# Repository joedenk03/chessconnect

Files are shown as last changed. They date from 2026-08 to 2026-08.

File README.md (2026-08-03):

# ChessConnect

A self-contained physical chess board that lets a local player face any Lichess.org
opponent over the internet, with both players' moves relayed to the physical board
in real time.

Senior capstone project at the University of Pittsburgh at Johnstown, 2024–2025.

https://github.com/user-attachments/assets/ddd3d065-473c-4527-940a-21a858fc336b

*Live demo at the University of Pittsburgh at Johnstown Senior Capstone Showcase — Joseph and Brendan walk through the system while playing a live game (Joseph on the physical board, Brendan on Lichess).*

## What It Does

ChessConnect combines a traditional wooden chess board with an internal
Cartesian gantry and electromagnet, allowing a local player to physically move
pieces against a remote opponent playing over Lichess.org — with no additional
software required on the remote player's end.

* The **local player** moves pieces normally. Reed switches under every square
detect the moves; the Arduino interprets them and sends them to Lichess.
* The **remote player** moves in their Lichess app or browser. When their move
arrives, the internal XY gantry positions an electromagnet under the piece,
turns on, drags the piece to its destination, and turns off.
* The **LCD screen** displays the in-game clock, current game status, and
handles the game setup UI (opponent selection, time controls, etc.).
* The system operates as a standalone device — once linked to a Lichess
account and connected to WiFi, it needs no external computer, phone, or app.

## Photos

|||
|-|-|
|Board playing view|Internal gantry|
|External playing view|Internal cabinet with XY gantry, electromagnet, and reed switch matrix|

## System Overview

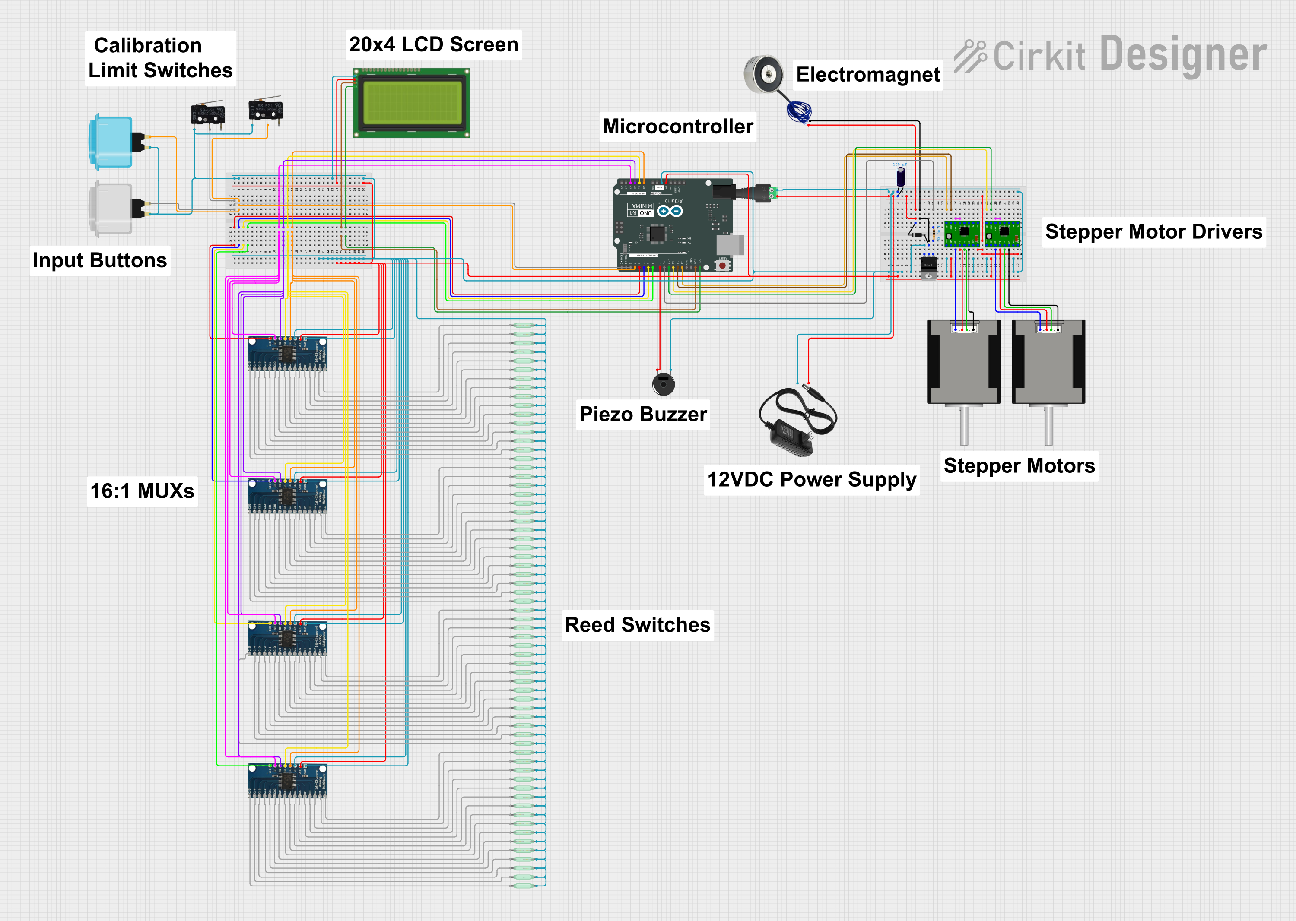
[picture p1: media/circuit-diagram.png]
Circuit diagram


### Key Components

|Component|Role|
|-|-|
|Arduino Uno R4 WiFi|Main microcontroller — inputs, game logic, Lichess API integration|
|Reed switch matrix (8×8)|Detects piece presence on each square via magnets in each piece base|
|4× 16:1 analog multiplexers|Read the 64 reed switches with a small pin budget|
|XY stepper gantry|Positions the electromagnet beneath the board|
|Electromagnet (TIP120 BJT drive)|Attracts pieces from below for automated moves|
|2× stepper drivers + steppers|Drive the X and Y axes of the gantry|
|20×4 LCD|Game setup UI, clock display, status messages|
|Limit switches|Homing and calibration for the gantry|
|Push buttons|User input for menu navigation|

Full block diagram and component descriptions in the capstone poster
([media/poster.pdf](media/poster.pdf)).

## Repository Structure

```
chessconnect/
├── README.md
├── .gitignore
├── firmware/
│ ├── chessconnect.ino
│ ├── secrets.h.example
│ └── secrets.h (local file, gitignored)
├── media/
│ ├── topdown-view.jpg
│ ├── internal-view.jpg
│ ├── circuit-diagram.png
│ └── poster.pdf
├── hardware/
│ └── models/
│ ├── stl/
│ │ ├── king.stl
│ │ ├── queen.stl
│ │ ├── rook.stl
│ │ ├── bishop.stl
│ │ ├── knight.stl
│ │ └── pawn.stl
│ └── fusion/
│ ├── king.f3d
│ └── ...
└── docs/
├── design-report.pdf
├── functional-requirements.pdf
├── testing-and-analysis.pdf
├── final-report.pdf
└── final-presentation.pdf
```

## Piece Fabrication

The playing pieces are 3D-printed from custom CAD models designed in Fusion 360.
Each piece has an embedded neodymium magnet in its base to interact with the
reed switches and be moved by the internal electromagnet.

CAD source files and print-ready STLs are in [`hardware/models/`](hardware/models/).

https://github.com/user-attachments/assets/cc7fb758-c390-4b25-9f52-523a92acfec9

## Firmware

The main firmware lives in [`firmware/chessconnect.ino`](firmware/chessconnect.ino).
It runs on an Arduino Uno R4 WiFi and handles:

* Setup and calibration of the XY gantry via limit switches
* Reed switch matrix scanning through four 16:1 muxes to detect piece positions
* Internal chess board state tracking and legal move interpretation
* Lichess REST API integration for game creation, move submission, and game
state streaming (`/api/challenge/`, `/api/board/game/`, `/api/board/game/stream/`)
* Motor control routines for file, rank, and diagonal moves via the AccelStepper
library, including special-case handling for castling and en passant
* LCD UI for game setup (opponent selection, time controls) and in-game display
(clock, status, error messages)
* Electromagnet control via a TIP120 BJT driver

### Building and Running

The firmware requires several Arduino libraries:

* **WiFiS3** and **WiFiSSLClient** — Arduino Uno R4 WiFi networking
* **ArduinoJson** — parsing Lichess API responses
* **LiquidCrystal_I2C** — 20×4 LCD control
* **AccelStepper** — stepper motor control with acceleration profiles
* **Wire** — I²C for the LCD

Before building:

1. Copy `firmware/secrets.h.example` to `firmware/secrets.h`
2. Fill in your WiFi SSID, WiFi password, and Lichess personal API token
(create a token at https://lichess.org/account/oauth/token with scopes
`challenge:read`, `challenge:write`, `board:play`)
3. Open the sketch in the Arduino IDE and upload to an Arduino Uno R4 WiFi

`secrets.h` is gitignored — it will not be tracked by git or pushed to any
public repository.

## Validation

ChessConnect was validated against a set of functional requirements defined
during the design phase. Testing included:

* Full games played against Lichess opponents (both human and bot), with
dozens of complete games recorded during system testing
* Verification of all special moves (castling, en passant, promotion)
* Board calibration procedures across multiple power cycles
* Error handling for illegal moves and mid-game piece disruption
* Automated piece movement speed verification (below)

https://github.com/user-attachments/assets/c93962c8-b26c-460b-896f-1c7d04267033

*Piece movement speed verification: an automated capture demonstrating the XY gantry, electromagnet timing, and post-move board state recognition. Used to verify the piece movement speed functional requirement.*

Full validation results in [`docs/testing-and-analysis.pdf`](docs/testing-and-analysis.pdf).
The complete project write-up, including background, design decisions, and outcomes, is in [`docs/final-report.pdf`](docs/final-report.pdf).

## Team

ChessConnect was developed as a senior capstone project by
**Joseph Denk** and **Brendan Jugan**, advised by Dr. Laura Wieserman,
at the University of Pittsburgh at Johnstown (2024–2025).

**Contribution breakdown:**

* **Joseph Denk** (this repository owner): Hardware design and fabrication —
board construction, circuit design and assembly, component selection and
specification, breadboard prototyping, mechanical integration. Firmware
contributions including architectural and program-flow input and
implementation of specific subsystems.
* **Brendan Jugan**: Primary firmware development, Lichess.org API integration,
game state management, and user interface logic.

Both team members contributed to overall system design, testing and
validation, and documentation.

## Documentation

The [`docs/`](docs/) folder contains the full set of project deliverables:

- [`design-report.pdf`](docs/design-report.pdf) — pre-build design phase report covering
  system architecture, component selection, and initial design decisions
- [`functional-requirements.pdf`](docs/functional-requirements.pdf) — formal specification
  of what ChessConnect had to do to be considered complete
- [`testing-and-analysis.pdf`](docs/testing-and-analysis.pdf) — verification results showing
  ChessConnect functioned as intended
- [`final-report.pdf`](docs/final-report.pdf) — complete project write-up covering the full
  year of design, construction, testing, and outcomes
- [`final-presentation.pdf`](docs/final-presentation.pdf) — capstone presentation slide deck

## License

Source code and documentation are provided as-is for portfolio and educational
purposes. Not affiliated with or endorsed by Lichess.org.

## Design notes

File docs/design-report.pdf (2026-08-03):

CoE 1195 Senior Project

ChessConnect

Final Design

Joseph Denk and Brendan Jugan

Department of Electrical and Computer Engineering

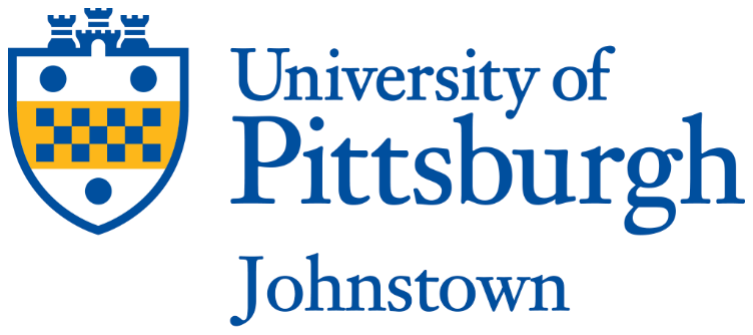
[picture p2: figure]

December 13th, 2024

Submitted to Dr. Laura Wieserman

CoE 1195 Senior Project

ChessConnect

Final Design – Bill of Materials

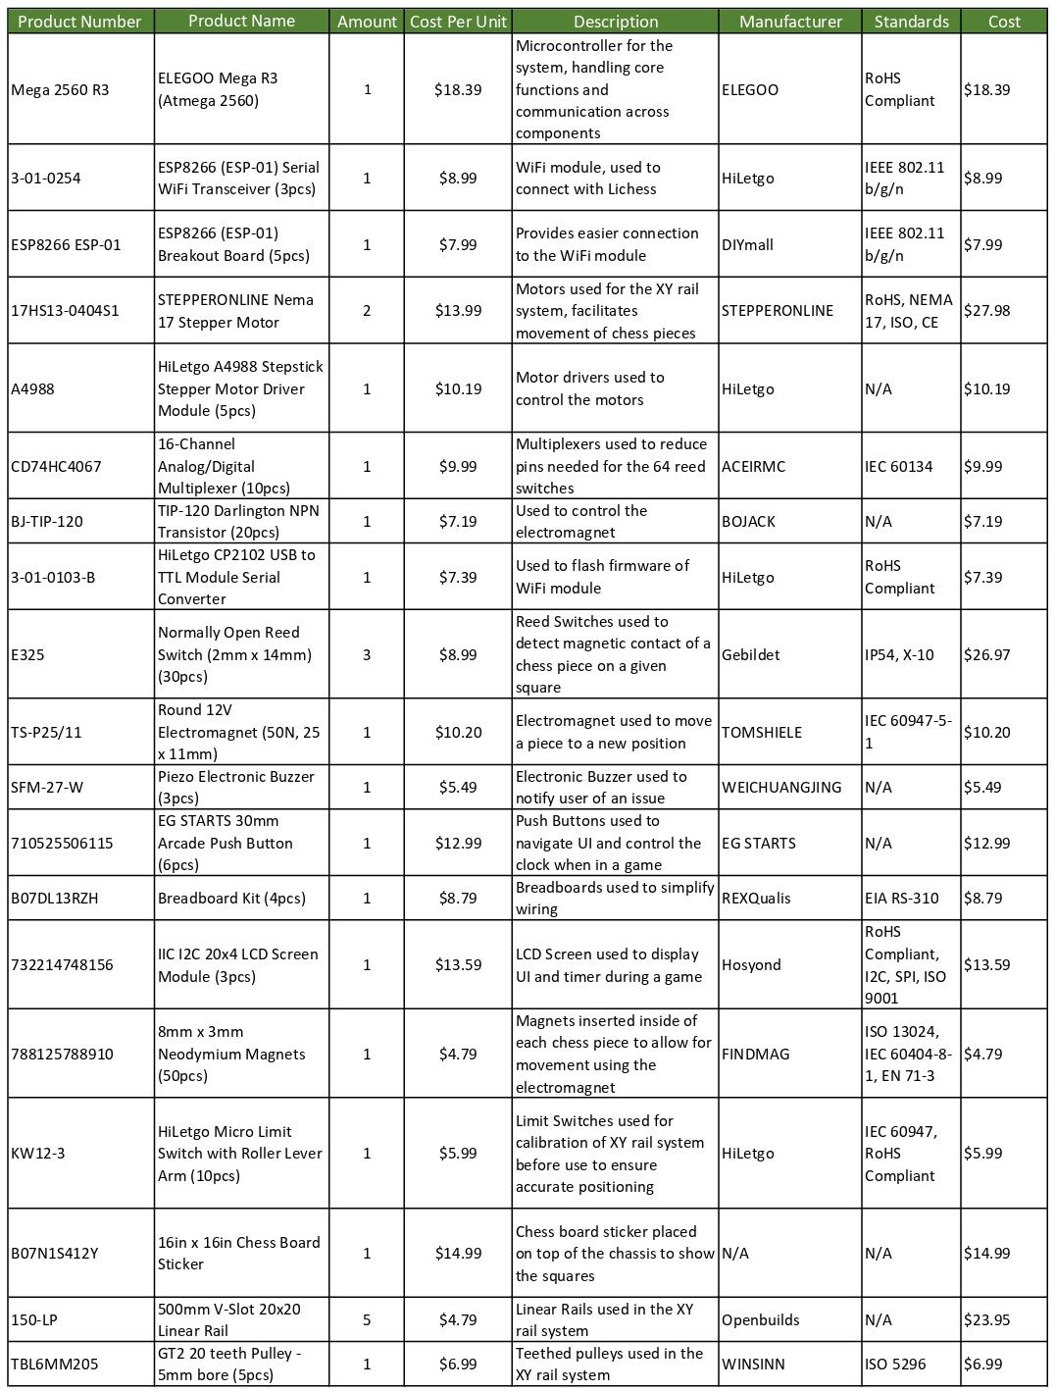
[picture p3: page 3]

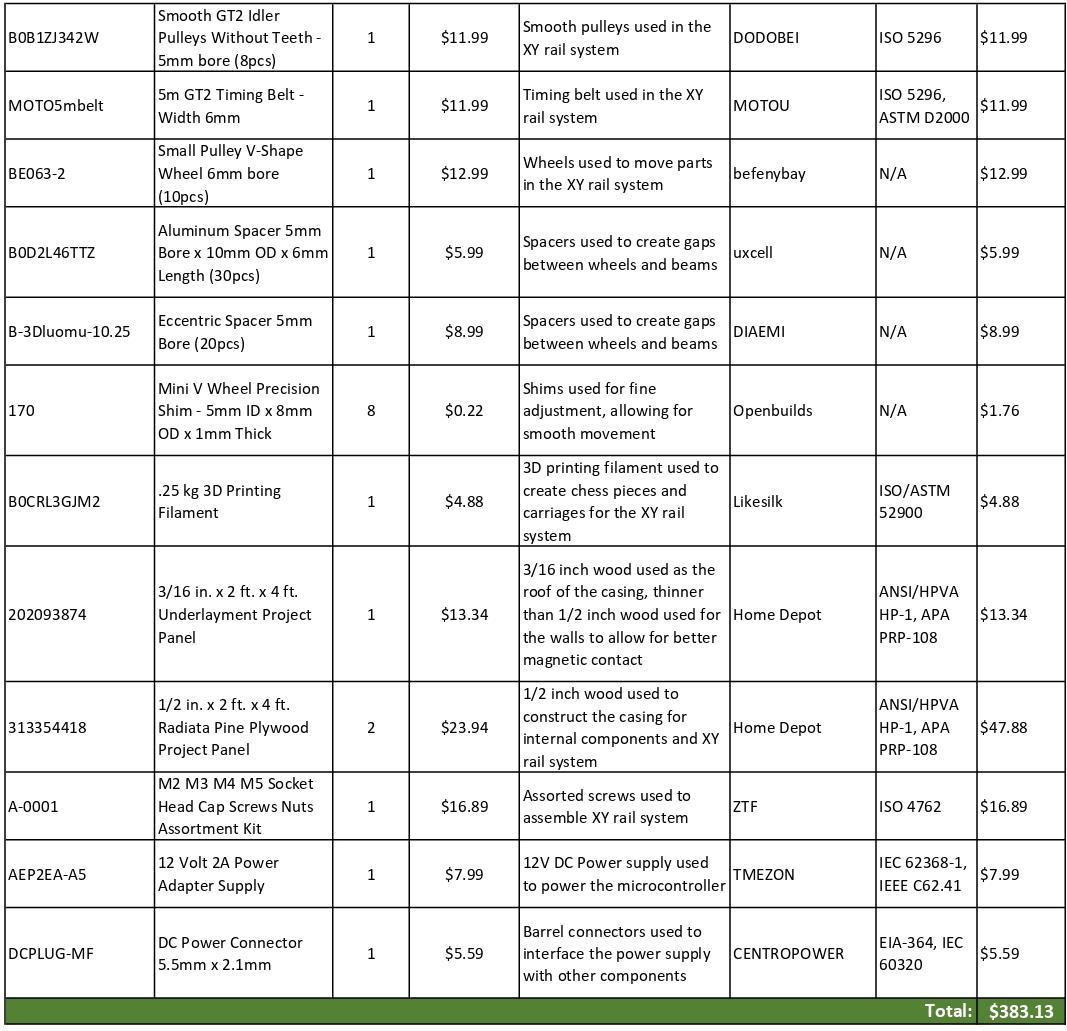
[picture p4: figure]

CoE 1195 Senior Project

ChessConnect

Final Design – Circuit Diagram

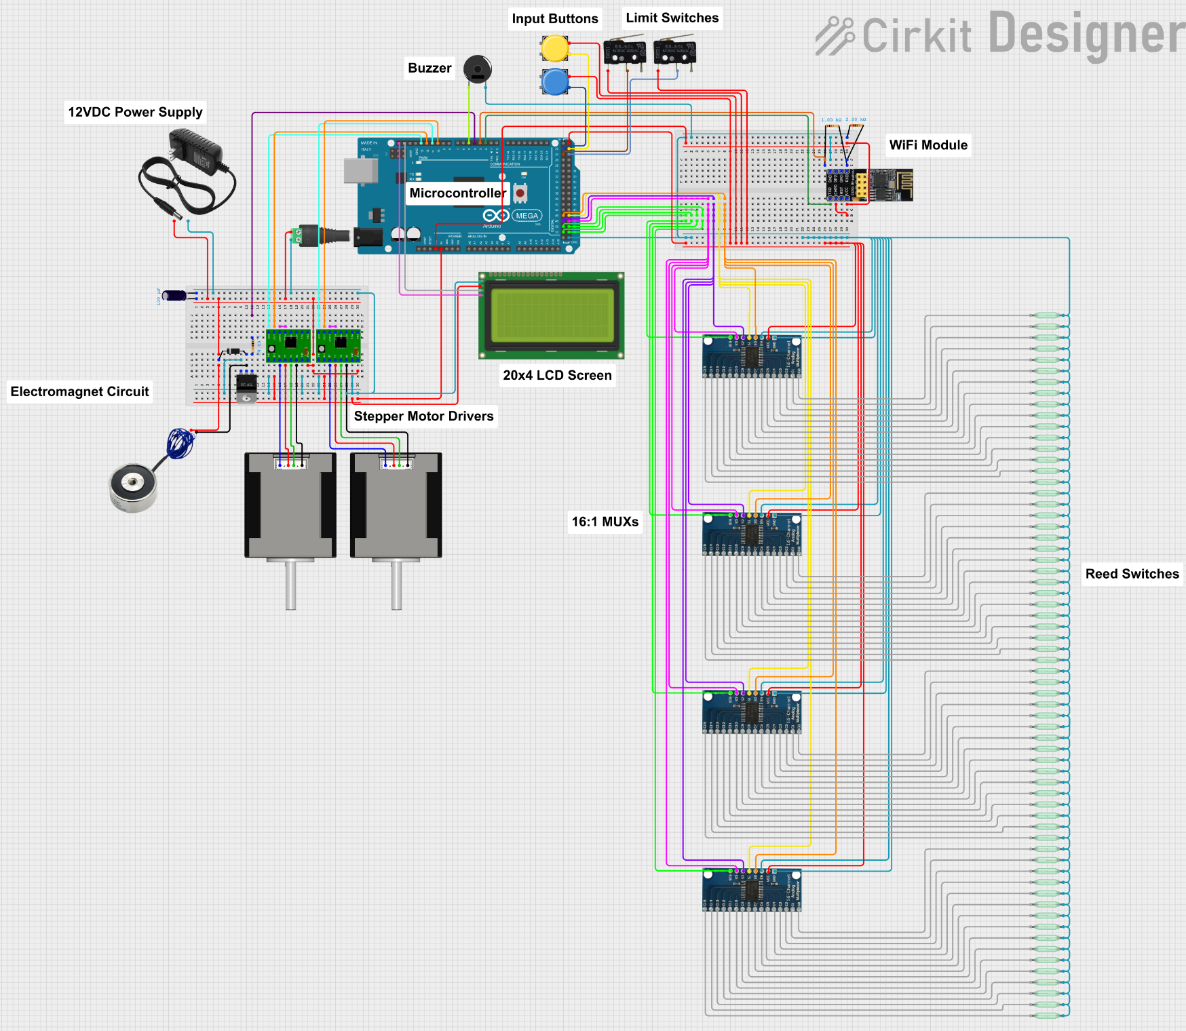
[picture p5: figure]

CoE 1195 Senior Project

ChessConnect

Final Design – Design Schematics

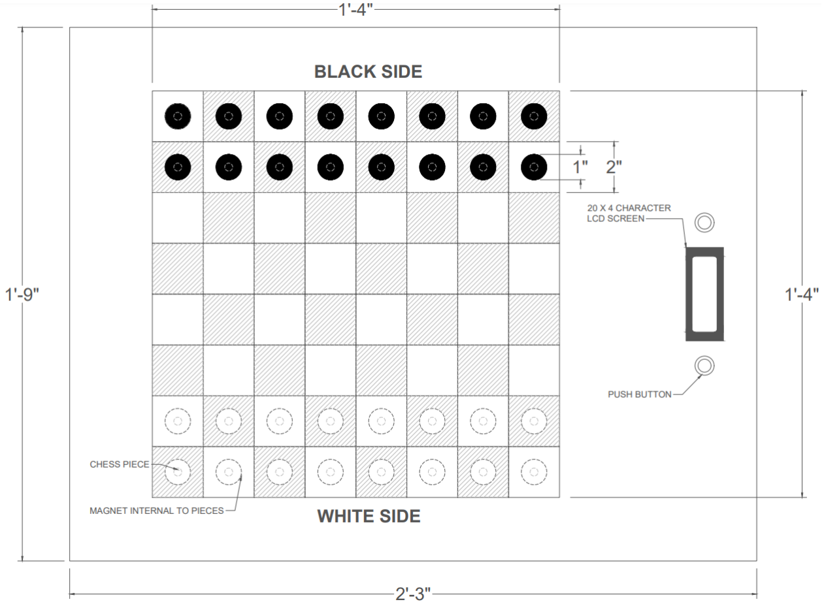
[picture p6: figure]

Fig. 1: Overall view of ChessConnect

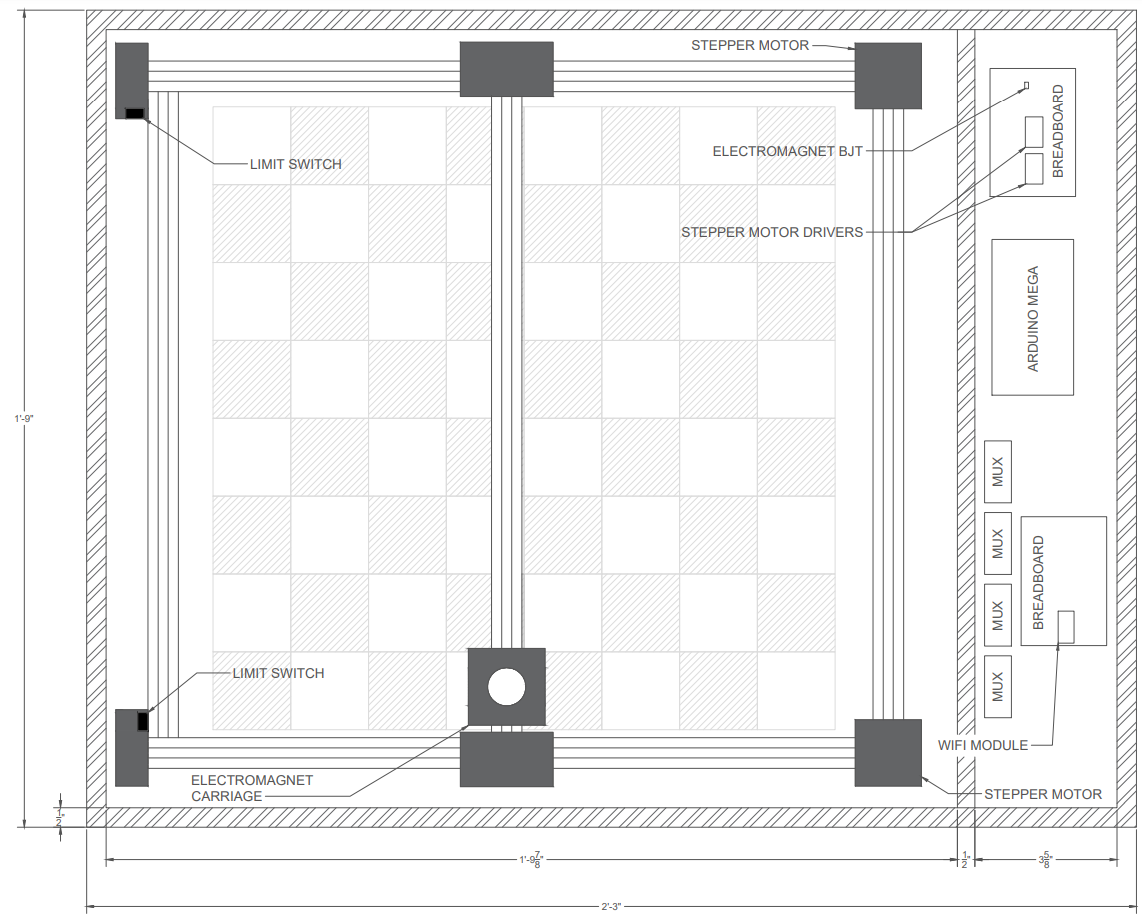
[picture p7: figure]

Fig. 2: Internal view of ChessConnect

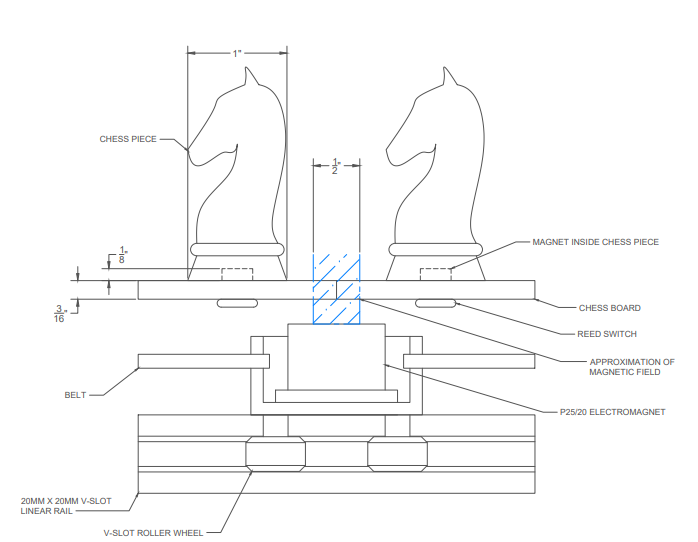
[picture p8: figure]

Fig. 3: Enlarged side view of ChessConnect

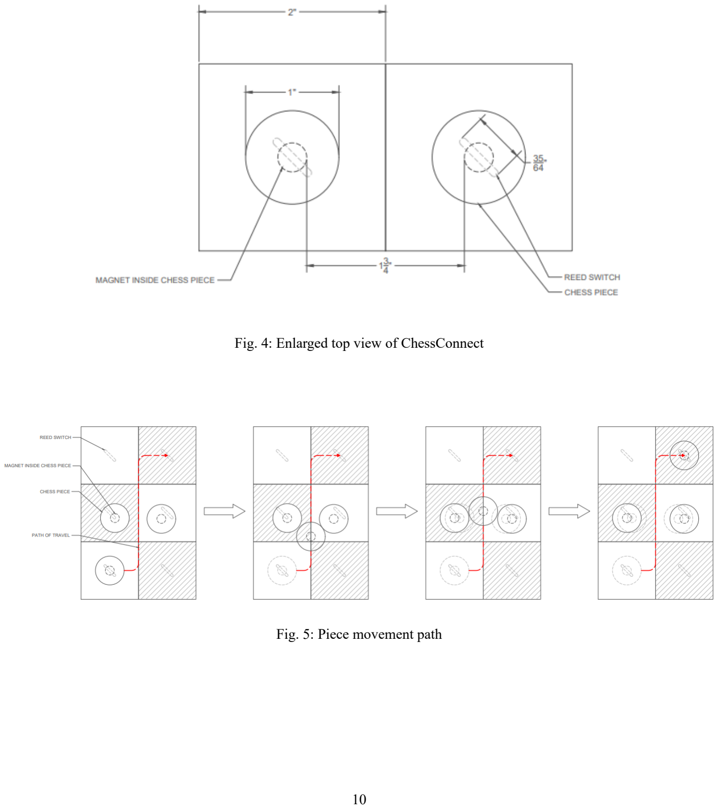
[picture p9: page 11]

Fig. 4: Enlarged top view of ChessConnect

Fig. 5: Piece movement path

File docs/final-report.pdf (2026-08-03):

## CoE 1199 Senior Project

## ChessConnect

## Final Report

## Joseph Denk and Brendan Jugan

## Department of Electrical and Computer Engineering

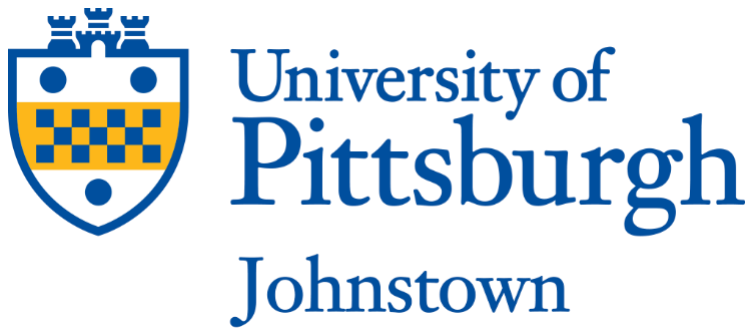
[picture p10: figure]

## April 28th, 2025

## Introduction

Chess is a game that is traditionally played over-the-board, but as humanity has

transitioned into the digital age the game has undergone many transformations that have affected

how players experience it. The most apparent of these changes has been the rise of online chess.

With the popularity of personal computers and phones, more and more people are turning to

digital chess and abandoning the traditional format.

As a result, the two formats have evolved in ways that have made them increasingly

distinct from one another. Online chess is often more convenient for users, providing them with

the ease of finding a game against an opponent of similar skill within seconds. Despite this

convenience, the format also comes with drawbacks that can impact one’s performance. For

example, many players find it easy to get distracted while playing online chess due to being

plagued by notifications, pop-ups, and advertisements which can easily break their focus. This

shorter attention span is also highlighted by the fact that online chess players prefer games with

shorter time controls. Online, fast-paced games do not effectively give players time to fully

calculate long sequences of moves and figure out a plan — a skill that is necessary for longer

time controls, which are typically used in over-the-board games. These differences in pace and

environment illustrate some of the broader distinctions between online and traditional chess;

however, even the core skillset required to play differs between the formats.

In traditional chess, players study and visualize a physical, three-dimensional board. In

contrast, online chess requires visualization of a two-dimensional board shown on a screen. The

pattern recognition necessary to visualize the board for each format is very different, as the

physicality of over-the-board games requires a level of spatial awareness that is not present when

playing online games. As such, the two formats require distinct ways of thinking and recognizing patterns. This becomes apparent when online users play an over-the-board game, wherein they

may struggle with visualizing potential moves and vulnerabilities to their pieces. Many online

chess platforms even give users the ability to draw arrows on their board, removing a key aspect

of the visualization required when playing an over-the-board game. As a result, these differences

between the two formats often make it difficult for one to transition from online to traditional

chess without facing challenges stemming from both digital and physical limitations.

The solution to this disparity is to create an electronic chess set that can be used to

translate virtual chess games into the physical realm and vice versa. Combining the aspects of

both online and traditional chess requires a specific balance between electronic assistance and

additional complexity to the traditional chess experience. This must be achieved while ensuring

the product remains convenient, easy to use, and affordable. It is this balance that ChessConnect

strives to achieve.

## Solution

ChessConnect is an electronic chessboard designed to bring a new and innovative

experience to chess players. Using the board, a chess game can be played against an online

opponent while the ChessConnect user plays on a physical board. When the user makes a move,

the board will automatically relay it to the opponent’s online game. Similarly, when the online

opponent makes a move, the pieces on the physical board will automatically move to their

updated positions. In doing this, ChessConnect allows for the convenience of online chess games

while allowing users to form good habits that are built from playing physical chess games.

As initially proposed, ChessConnect was intended to connect to an online chess service

using an Arduino Mega microcontroller along with a WiFi module. Once the board has an

established connection, the board would then connect to Chess.com to allow the user to play against online opponents while at a physical board. Move detection for the user would be done

using reed switches placed on each chess square on the underside of the board. These reed

switches would interface with magnets internal to each chess piece so that the state of the board

can be tracked in real time by scanning these switches. Once it becomes the opponent’s turn, the

board would connect with Chess.com and wait for a move to be sent by the opponent. Once a

move is sent, an internal gantry with an attached electromagnet would position itself under the

piece to be moved. It would then move this piece by turning the electromagnet on and moving to

the piece’s destination square. In the case of taking pieces or knight movement, pieces would be

sized to allow for movement on the border of squares without interfering with other pieces on the

board.

However, now that the device has been built, changes have been made to the preliminary

design of the device. The device functions nearly the same as proposed, with little to no

functional changes being made to the core concept of the project. However, a change needed to

be made to the server on which the ChessConnect user will play games. Originally, the device

was to connect to Chess.com, but during testing, it was determined that the Chess.com API was

very closed off to the public. To gain access to the API, multiple steps of documentation were

needed and resources pertaining to the use of the API were sparce. As a result, Lichess.org,

another large online chess service with an open access API, was determined to be a more suitable

server to be used for the device. This API also came with extensive documentation and examples

which made implementation much less time consuming. Along with the server change, hardware

modifications were also made to the device to make online capabilities possible. During testing,

the project group determined that the Arduino Mega and WiFi module are not capable of

interfacing with the Lichess server. While these components can successfully connect to WiFi networks and connect to multiple online servers, they are incapable of connecting to Lichess due

to the type of connection encryption used with their servers. To connect to Lichess, a root

certificate must be stored in the microcontroller, and the Arduino Mega lacks the processing

power and memory to handle this encryption process. To resolve this, the Arduino Mega and

WiFi module was returned and substituted with an Arduino UNO R4 WiFi. This microcontroller

was chosen due to its built-in ESP32 chip which is capable of interfacing with encrypted servers

like Lichess. These changes were crucial to the successful implementation of online connectivity

onto the physical board.

## Results

The completed ChessConnect system successfully fulfills its intended functionality of

bridging the gap between online and traditional chess formats. Once powered and connected to

WiFi and a Lichess.org account, the board enables users to start a new game directly from the

onboard interface. Once the match begins, the board operates exactly as specified during the

design phase. When it is the opponent’s move, the internal gantry will move under the moving

piece’s square, take it to its new square without interfering with uninvolved pieces on the board,

and position it on the destination square. When it is the user’s turn, the board will continuously

scan the reed switches and update the board state until a change is made. If the user does not

wish to make a move and wants to view options, they can browse a brief options menu allowing

them to resign the game or adjust pieces manually if many pieces have been knocked off their

space. Otherwise, once a piece is picked up, it will be determined whether the user is taking a

piece or not along with allowing them to return their piece back to its original square and make a

different move if they wish. Once a move is made, it is sent to the Lichess server and reflected in the ongoing online game. This bidirectional synchronization enables a seamless playing

experience and gives users the benefits of both online and traditional chess formats.

In addition to the core features, ChessConnect accounts for special cases that can happen

during a chess game. All unique chess moves are accounted for when making an automatic move

on the board or a user move which ensures that any type of move can be played. Furthermore, if

the user makes an illegal move, the board includes safeguards to maintain the gameplay flow and

allow the user to remedy their mistake. If an illegal move is made, the user is informed of the

invalid move via the LCD screen and prompted to put the piece(s) back. Once they have done

this, they can return to the gameplay and make another move as if the illegal move had never

happened.

## Conclusion and Recommendations

ChessConnect has reinforced many ideas and techniques learned throughout the

curriculum at the University of Pittsburgh at Johnstown. These include many different hardware

and circuit design skills, microcontroller coding and usage, and general software implementation

and practices. Along with concepts, many new skills were developed by the group members to

complete the project. These skills include soldering, API integration/interfacing, and automation

controls. The team also developed crucial testing skills which were required to take

ChessConnect from an interesting concept to a functioning prototype. For example, extensive

testing needed to be conducted surrounding the magnetic interactions that allowed the device to

work. The project team had to repeatedly test and adjust the various implementations of the

magnetic switches, electromagnet, and internal piece magnets to strike a balance that was not

only functional but also consistent. These tests also expanded the team’s knowledge of various

magnetic technologies which provided valuable insight into future changes which could potentially improve the device’s functionality. Overall, ChessConnect proved not only to be a

successful project but an important learning experience that highlighted the importance of

adaptability, hands-on development, and continuous learning.

Looking ahead, there are some future improvements that can be made to ChessConnect to

enhance the gameplay experience for the user. General build quality improvements would

greatly help not only with the overall appearance of the device but also improve functionality in

nearly all areas. Better reed switches and more suitable material to construct the chassis would

allow for more consistent piece detection, and better motors, perhaps with dampening, could also

be used in the future to reduce the vibration and sound produced during gantry movement.

Another future consideration is compatibility with different chess servers and game modes. In

the future, the project group would like to interface with other online servers like Chess.com to

allow users to have the most freedom when choosing how to play. Also, more game modes could

be implemented in the future such as game modes with unique starting positions or the

development of a ChessConnect specific game mode.

## Hardware Appendices

### Description of Components

Listed below are descriptions of the core hardware components of ChessConnect and the

function they serve to the overall device. The interaction between these components is expanded

upon in the following section – the block diagram.

Arduino UNO R4 WiFi - The Arduino microcontroller enables connection to Lichess and

acquires data from the various inputs to facilitate the user interface (UI) as well as interpret the

user’s chess moves which are then sent to the online game. Similarly, it converts the opponent’s

move from the online game into the corresponding sequence of motor and electromagnet

controls that update the piece positions.

LCD Display - The LCD Display facilitates all direct communication with the user, allowing

them to traverse through the game mode selection, check their move before sending, display

errors or illegal moves, and view options during a game.

Speaker - The internal speaker is a small, two wire piezo buzzer used solely for making simple

beeps when a piece is not detected on its destination square after an automatic move.

12V DC Power Supply - The power supply is used to convert 120V AC power from a common

wall outlet into the 12V DC power needed for various components.

Push Button (x2) - The push buttons are located on the black and white sides of the LCD

display. They are used by the user to navigate various options listed on the LCD display and to

send a move.

BJT – TIP 120 - The TIP-120 bipolar junction transistor (BJT) functions as a control switch for

the electromagnet. The higher current and voltage demands of the electromagnet necessitates that

it is powered from the 12V supply directly instead of from the Arduino pins. By connecting the

base pin of the BJT to the microcontroller and routing the supply power to the electromagnet

through the collector and emitter pins, the Arduino can control when the current to the

electromagnet flows.

Electromagnet - The electromagnet is used on the internal gantry to control piece movement.

When the opponent’s move is received, the magnet will be positioned beneath the piece, turn on,

and hold the piece as it is moved to its destination.

Stepper Motor Driver (x2) - The stepper motor drivers are used to operate the motors for the

XY rail system. These motor drivers take instructions from the microcontroller and convert them

into movements that the motor can perform.

Stepper Motor (x2) - The motors are used to facilitate the movement of the electromagnet

mounted on the XY rail system and allows for piece movement.

Reed Switch (x64) - The Reed switches are used to track the positions of the pieces during a

game. These switches are located under every square of the board, allowing them to interact with

the internal magnets of each piece. By tracking the changes in which switches are closed or open,

the microcontroller can detect how the user moves their pieces.

MUX (x4) - The 16-channel multiplexers are used to reduce the number of pins necessary to

connect the 64 reed switches to the microcontroller.

Micro Switch (x2) - The micro switches are mounted onto the gantry and are used as limit

switches for calibration. They are placed in specific positions such that the rail system can move

the electromagnet to the furthest corner of the rail system. This allows the electromagnet to have

a known position to move from

### Block Diagram

The block diagram shown below in Figure 1 details the connections between the

hardware components of ChessConnect.

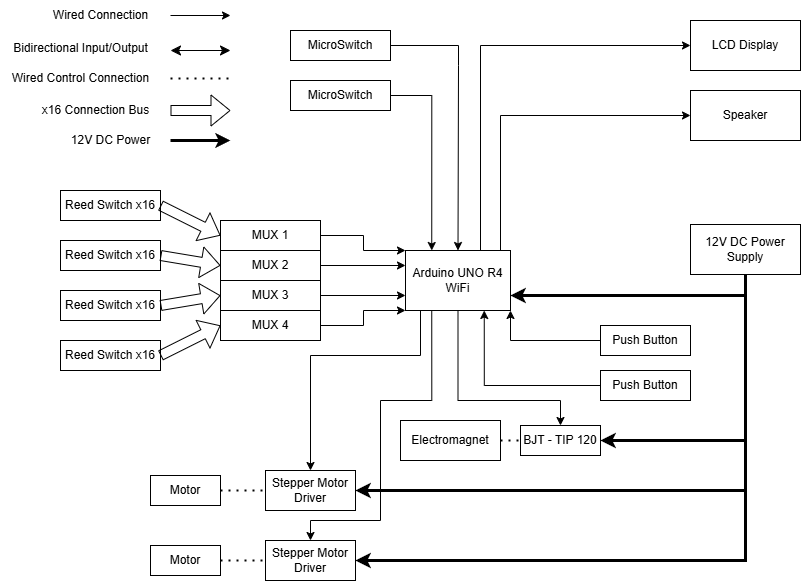
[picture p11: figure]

Fig. 1. Block Diagram

### Circuit Diagram

The circuit diagram shown below in Figure 2 outlines the connections between each

hardware component described above.

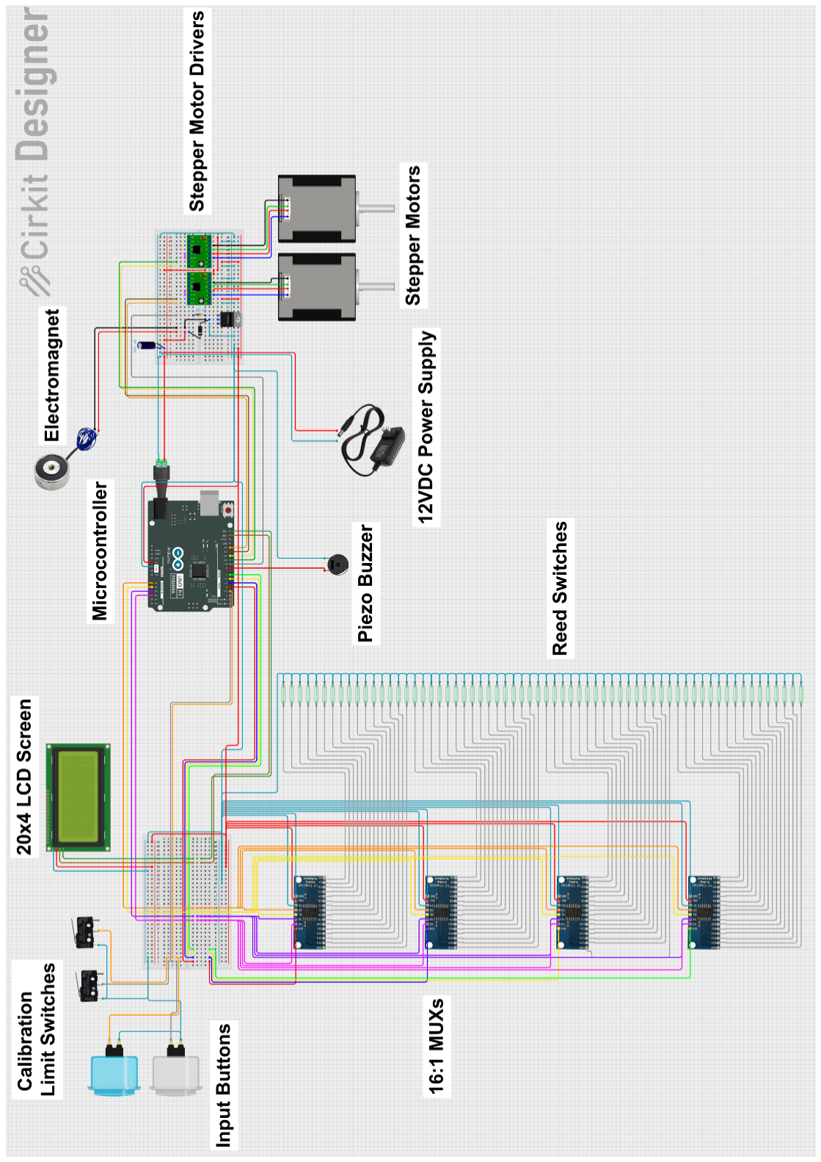
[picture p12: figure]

Fig. 2. Circuit Diagram

### Device Schematics

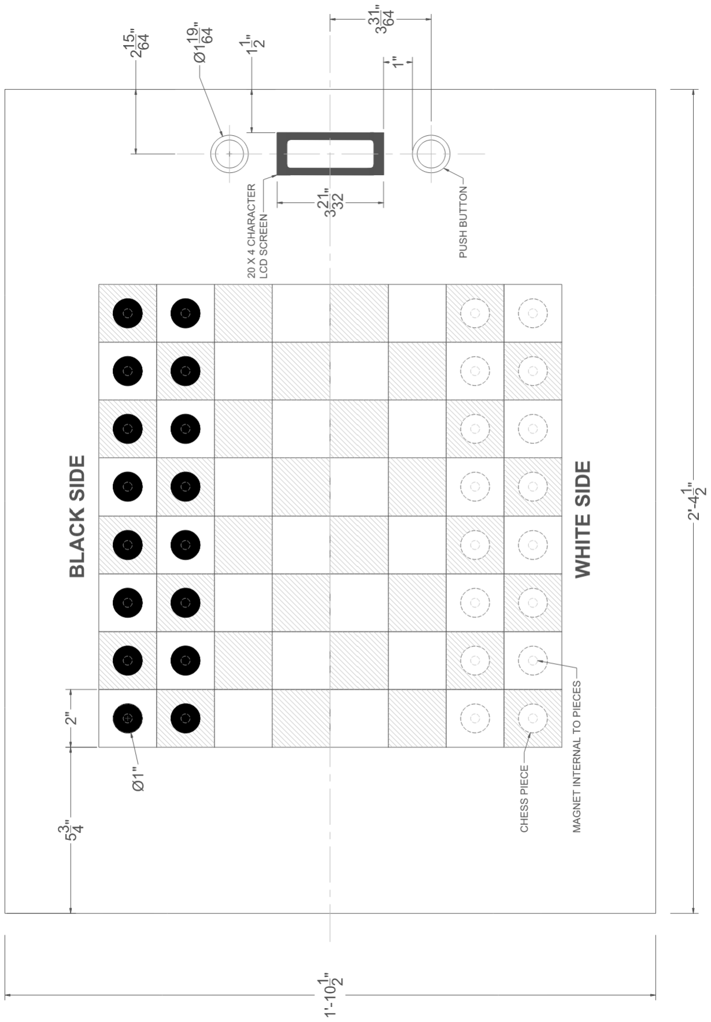
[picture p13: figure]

Fig.

3. External View

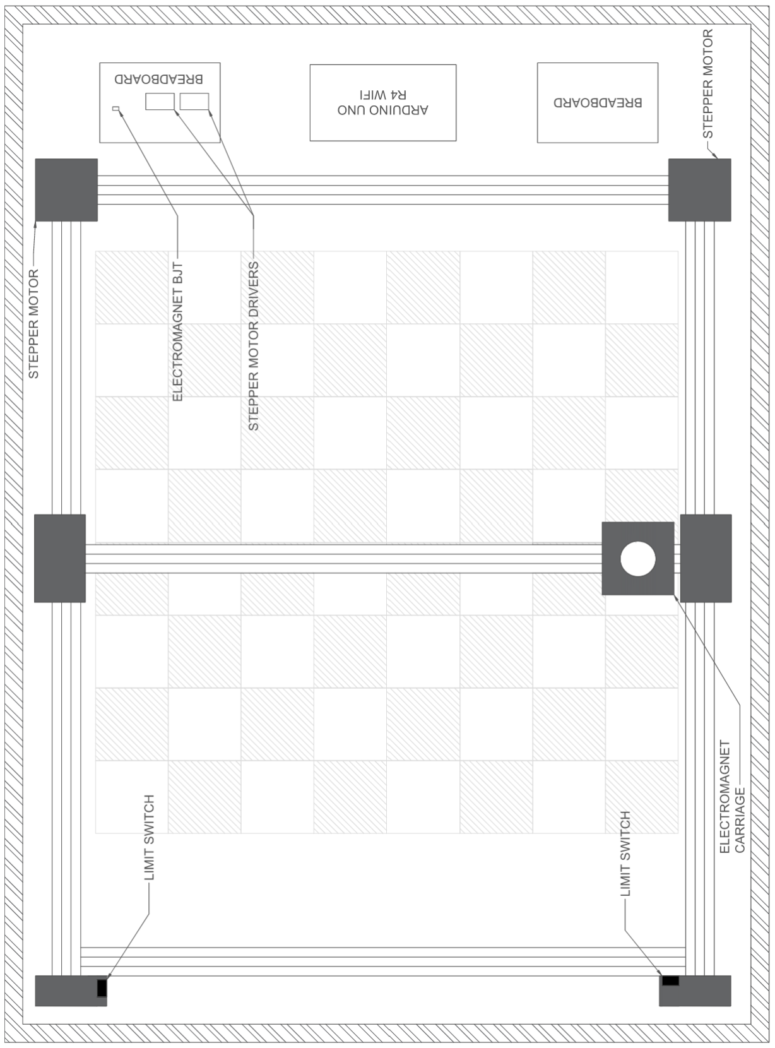
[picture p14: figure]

Fig. 4. Internal View

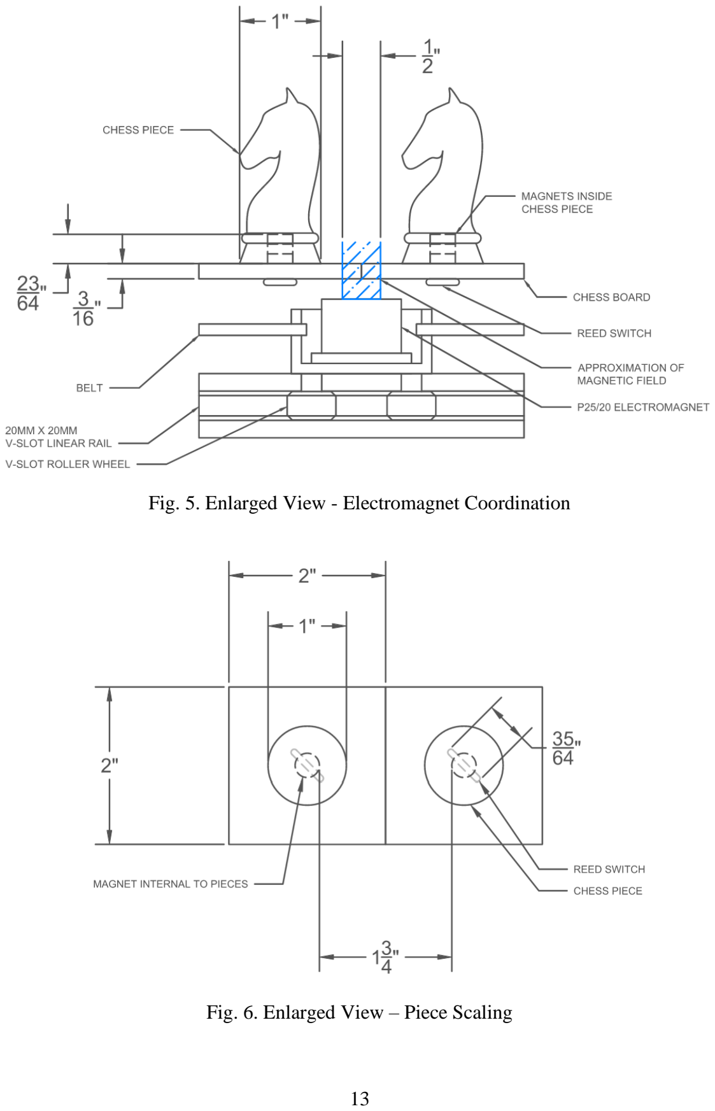
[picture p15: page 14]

Fig. 5. Enlarged View - Electromagnet Coordination

Fig. 6. Enlarged View – Piece Scaling

### Bill of Materials

The bill of materials is listed below in Table 1, outlining all materials used to create

ChessConnect and the associated information for each. The final material cost of ChessConnect

is $394.22.

Table 1: Bill of Materials

Product Name | Amount | Cost Per Unit | Manufacturer | Standards | Cost
Arduino UNO R4 WiFi | 1 | $27.99 | Arduino | RoHS Compliant | $27.99
STEPPERONLINE Nema 17 Stepper Motor | 2 | $13.99 | STEPPERONLINE | RoHS, NEMA 17, ISO, CE | $27.98
HiLetgo A4988 Stepstick Stepper Motor Driver Module (5pcs) | 1 | $10.19 | HiLetgo | N/A | $10.19
16-Channel Analog/Digital Multiplexer (10pcs) | 1 | $9.99 | ACEIRMC | IEC 60134 | $9.99
TIP-120 Darlington NPN Transistor (20pcs) | 1 | $7.19 | BOJACK | N/A | $7.19
Normally Open Reed Switch (2mm x 14mm) (30pcs) | 3 | $8.99 | Gebildet | IP54, X-10 | $26.97
Round 12V Electromagnet (100N, 30 x 22mm) | 1 | $12.00 | TOMSHIELE | IEC 60947-5-1 | $12.00
Piezo Electronic Buzzer (3pcs) | 1 | $5.49 | WEICHUANGJING | N/A | $5.49
EG STARTS OEM 30mm Sanwa Push Buttons (12pcs) | 1 | $11.99 | EG STARTS | N/A | $11.99
Breadboard Kit (4pcs) | 1 | $8.79 | REXQualis | EIA RS-310 | $8.79
IIC I2C 20x4 LCD Screen Module (3pcs) | 1 | $13.59 | Hosyond | RoHS Compliant, I2C, SPI, ISO 9001 | $13.59
8mm x 3mm Neodymium Magnets (50pcs) | 3 | $4.79 | FINDMAG | ISO 13024, IEC 60404-8-1, EN 71-3 | $14.37
HiLetgo Micro Limit Switch with Roller Lever Arm (10pcs) | 1 | $5.99 | HiLetgo | IEC 60947, RoHS Compliant | $5.99
500mm V-Slot 20x20 Linear Rail (10pcs) | 1 | $39.99 | MECCANIXITY | N/A | $39.99

GT2 20 teeth Pulley - 5mm bore (5pcs) | 1 | $6.99 | WINSINN | ISO 5296 | $6.99
Smooth GT2 Idler Pulleys Without Teeth - 5mm bore (8pcs) | 1 | $11.99 | 3Dman | ISO 5296 | $11.99
5m GT2 Timing Belt - Width 6mm | 1 | $11.99 | MOTOU | ISO 5296, ASTM D2000 | $11.99
Small Pulley V-Shape Wheel 6mm bore (10pcs) | 1 | $12.99 | befenybay | N/A | $12.99
Aluminum Spacer 5mm Bore x 10mm OD x 6mm Length (30pcs) | 1 | $5.99 | uxcell | N/A | $5.99
Eccentric Spacer 5mm Bore (20pcs) | 1 | $8.99 | DIAEMI | N/A | $8.99
.25 kg 3D Printing Filament | 1 | $4.88 | Likesilk | ISO/ASTM 52900 | $4.88
3/16 in. x 2 ft. x 4 ft. Underlayment Project Panel | 1 | $13.34 | Home Depot | ANSI/HPVA HP-1, APA PRP-108 | $13.34
1/2 in. x 2 ft. x 4 ft. Radiata Pine Plywood Project Panel | 2 | $23.94 | Home Depot | ANSI/HPVA HP-1, APA PRP-108 | $47.88
M2 M3 M4 M5 Socket Head Cap Screws Nuts Assortment Kit | 1 | $16.89 | ZTF | ISO 4762 | $16.89
12V 5A Power Supply | 1 | $9.99 | Waysse | IEC 62368-1, IEEE C62.41 | $9.99
DC Power Connector 5.5mm x 2.1mm | 1 | $3.80 | ZHLATECK | EIA-364, IEC 60320 | $3.80
M5 T Slot Nuts for Aluminum Profile (100pcs) | 1 | $5.99 | HELIFOUNER | N/A | $5.99
M5 x 20mm 25mm 30mm 35mm 40mm Button Head Socket Cap Screws Bolts | 1 | $9.99 | Cicidorai | N/A | $9.99
TOTAL: | $394.22i

### User Manual

ChessConnect has very few hardware components that interact directly with the user,

making the device extremely simple to use. The main areas of the device that the user should be

aware of are the device controls, I/O ports, and procedures for handling pieces. The guidelines

for interacting with these areas of the device and other useful information are as follows:

Device Controls – Operating ChessConnect requires only the use of two buttons and an LCD

screen which are located on the top panel of the chess board on the same side as the I/O. The

buttons are colored black and white to represent the corresponding black and white sides of the

chess board. The black and white sides cannot change, or the device will not work properly.

During navigation of the home-screen before a chess game has started, pressing the black button

will cycle through the various options on a given screen, and pressing the white button will select

an option and move the user to the next screen. To go to a previous UI screen, press the black

button to cycle through options until “Back” is selected, and press the white button to go back.

Once the ChessConnect user enters a game, they will be assigned to either black or white

randomly. The button that matches their assigned color is used to simultaneously send their

move into the online game and stop their chess clock. Pressing the opponent’s button during a

game will bring up an options menu that allows the user to send a game resignation or adjust

piece positions. Once in this menu, the opponent’s button will cycle through the various menu

options and the user’s button is used to select.

Input/Output Ports – The side of the chess board below the LCD screen and push buttons is

where the two I/O ports are located. Looking at the I/O side of the device, the port on the left is a

USB type C and the port on the right is a 2.1mm barrel plug that is used to supply 12V power to

the device. DO NOT USE ANY POWER SUPPLY THAT IS NOT RATED FOR 12V AND AT

LEAST 5A. Failure to comply with this requirement may result in loss of device functionality

and/or destruction of the device. The USB port is connected directly to the microcontroller and

can be used for debugging and updating the software which controls the board.

Setting Up/Moving Pieces – Once a game type has been selected, the ChessConnect user will be

prompted with a screen to set up the pieces on the board. This screen will show a list of the

squares for both the black and white sides that do not have a piece detected on them. At this

stage, the user must place all the pieces on their corresponding squares which will cause them to

be removed from the screen. Once a side has detected all its pieces, an “all good” message will

display. When all pieces on both sides are detected, the request to start a game with the

previously selected settings will automatically be sent to Lichess.org. To ensure accurate move

detection, the board will print the source and destination square of a piece as the user makes a

move. When the user first picks up a piece, they must verify that the screen displays the starting

square. Placing the piece back on the starting square will cancel the move that is in progress.

When the piece is placed on the destination square, the screen will display the full move and

prompt the user to press their button to send the move to the online game. Pressing the

opponent’s button will cancel the move and wait for the user to place the piece on the source

square before making a new move. If the board is having issues detecting when a piece is picked

up or put down, the ChessConnect user should try lightly pushing the piece into the board and

moving it around the square. Doing this for every move will increase the consistency of piece

detection. The process of taking an opponent’s piece is very similar. The user must first pick up

the captured piece, at which point the board will display a “TAKING:” screen with the

destination square. Once the captured piece is removed, the capturing piece can be moved into

place following the same procedure as previously stated. Similarly, castling requires moving the king to its destination square first and then moving the rook into position after the screen

displays the king’s complete move. Note: pieces must be picked up clear of the board and placed

on their destination as opposed to sliding. Sliding pieces or hovering could result in incorrect

move detection. ChessConnect will automatically promote any pawns to queens. Once a pawn

has reached the opponent’s side of the board and the move has been sent, the user can replace the

pawn with a queen without causing any issues.

### Acceptance Testing Procedure and Criteria

ChessConnect was deemed functional after a series of comprehensive tests performed by

both the project group and external testers. The primary functionality, quick and accurate piece

movement, was tested extensively.

Initially, isolated testing on the internal gantry was done to verify that it could move

pieces from within the board. This testing revealed various issues regarding electromagnet

strength, consistency of piece movement, and speed of piece movement. These issues resulted in

the project teaming making several changes throughout the construction of the device. A stronger

electromagnet was bought to overcome the air gap between the board surface and the

electromagnet itself as well as maintain the ability to hold onto the piece at higher speeds.

Additionally, a new piece magnet solution was established after testing various implementations

to determine a balance between piece detection and movement consistency. Finally, a new power

supply was ordered as a power limit was encountered while attempting to meet the threshold

value for automatic piece move time.

After these solutions were implemented, final testing was conducted to verify that the

engineering specifications were met and that all piece movements were consistent and accurate.

During final testing, full games were played on the board against opponents who were unfamiliar

with the device. This allowed the project group to observe the simplicity of the device and detect

any unforeseen issues. The engineering specification for piece detection errors was monitored

during these games and ended up being slightly above our threshold value. As a result, controls

were implemented to manually correct any detection errors. Furthermore, testing revealed that

repeated diagonal movements cause a reduction in movement accuracy, which caused the team

to implement periodic recalibration. As a software test, the project group tracked the internal

board state via the serial monitor as games were played. This allowed the group to observe

changes as moves were made and detect if the board state had any inconsistencies. Many issues

were found during these tests and were resolved to ensure that gameplay was seamless.

After all issues were resolved, outside testers continued playing games using the device.

These tests confirmed that the system was easy to use and provided seamless gameplay. The

comprehensive testing process, including internal and external evaluation, verified that the

system met its functional requirements and was ready for full use.

## Software Appendices

### Program Description

The program used to control ChessConnect was written in Arduino C++ and runs on the

Arduino UNO R4 WiFi. The program manages the operation of the internal gantry and

electromagnet for piece movement, scans reed switches for piece detection, and processes user

input from the push buttons. This functionality is integrated with game logic and online

communication through Lichess.org. Initially, a user can select their gameplay settings and start

a game using the push buttons. During a game, responses received from the Lichess server are

interpreted and relayed to the user via the LCD display to ensure synchronized gameplay

between the board and online opponents. Overall, the software successfully maintains consistent

game state tracking, handles movement control, and facilitates user interaction throughout chess

games.

### Software Flowchart

ChessConnect has three main routines used to achieve seamless gameplay. These routines

are game selection, opponent’s move, and user’s move. Software flowcharts describing these

routines, and how they interact, are shown below. Figure 7 outlines game selection, Figure 8

outlines the opponent’s move, and Figure 9 outlines the user’s move.

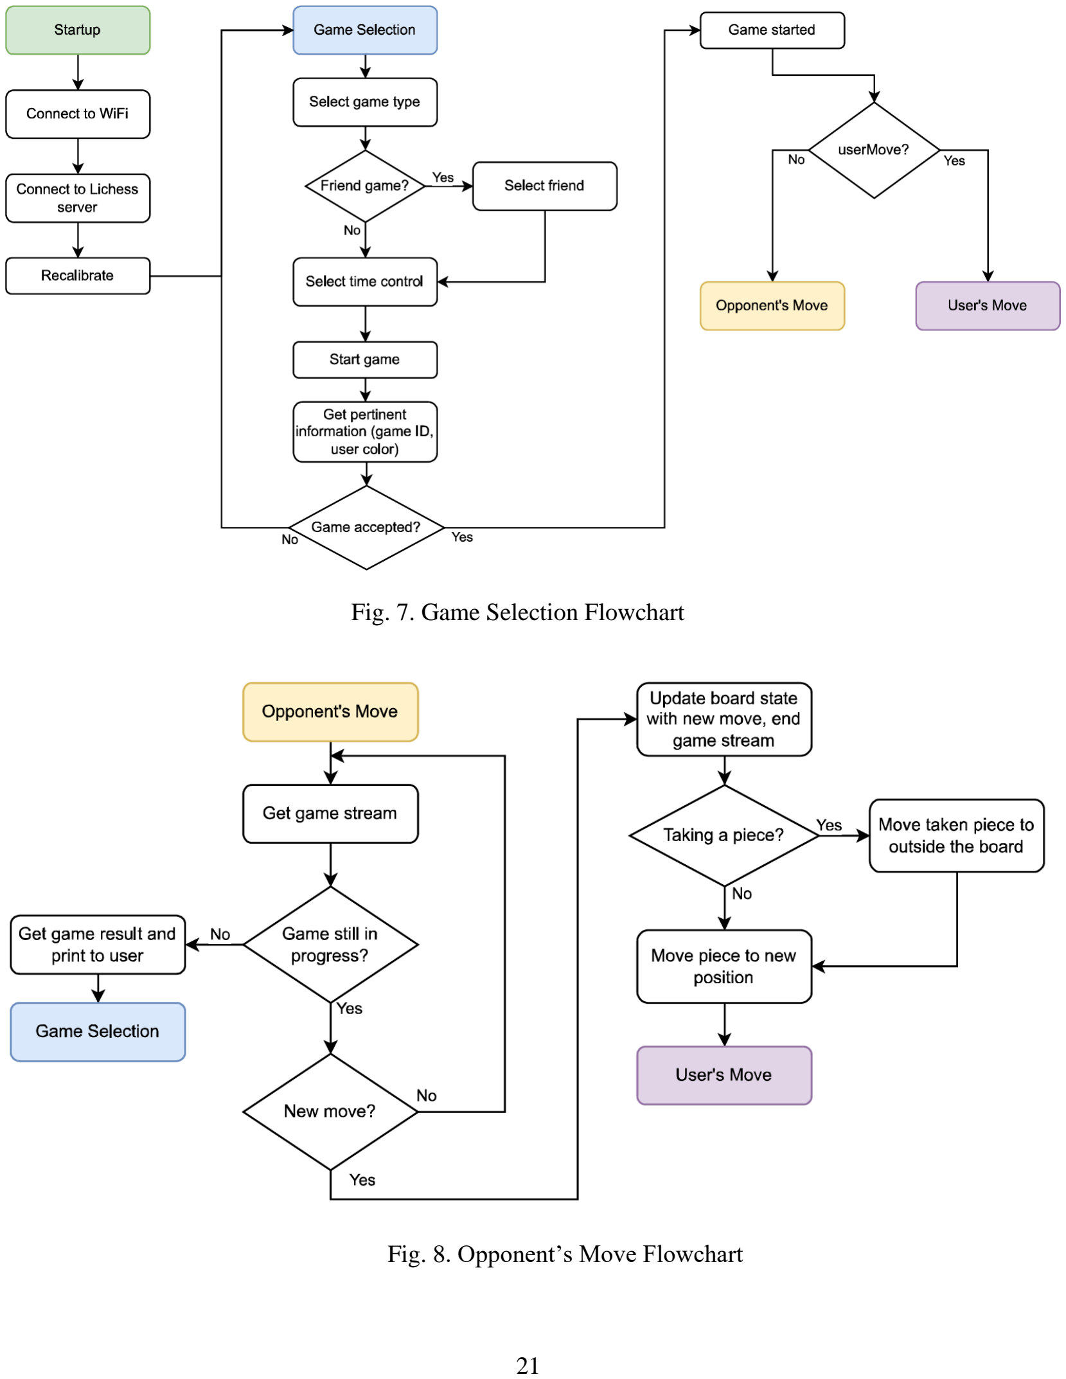
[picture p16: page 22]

Fig. 8. Opponent’s Move Flowchart

Fig. 7. Game Selection Flowchart

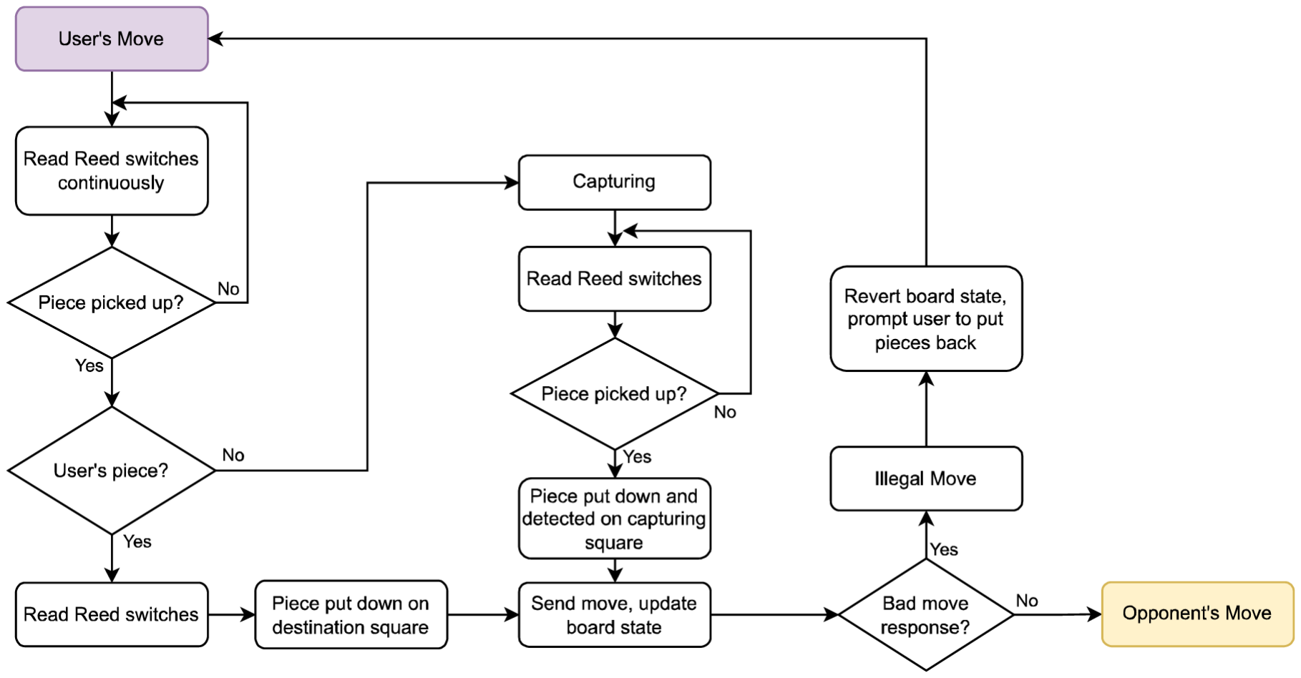
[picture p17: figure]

Fig. 9. User’s Move Flowchart

### Source Code

The complete source code for ChessConnect can be found in the project binder under Tab

#13 – Source Code.

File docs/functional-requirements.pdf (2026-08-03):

## CoE 1195 Senior Project

## ChessConnect

## Functional Requirements and Engineering Specifications

## Joseph Denk and Brendan Jugan

## Department of Electrical and Computer Engineering


## December 13th, 2024

## Submitted to Dr. Laura Wieserman

## Problem Statement

Chess is a game that is traditionally played over-the-board, but as humanity has transitioned

into the digital age, the game has undergone many transformations that have affected how

players experience it. More and more people are turning to digital chess options with one of the

most prominent being the website Lichess.org, which has facilitated over five billion standard

rated chess games and just shy of nine billion total chess games since its creation in 2010 [1].

Although the widespread popularity of online chess is undeniable, using these services results in

compromises that change the core of the game. Many players find it easy to get distracted while

playing chess online due to plagues of notifications, pop-ups, and advertisements which can

easily break their focus and lead to less precise play. Furthermore, this shorter attention span is

highlighted by the fact that online chess players have a preference to games with shorter time

controls. This contrasts with traditional tournaments played over-the-board which often give

hours for each side. Many experienced chess players confirm playing chess in the physical world

requires a different skill set. In her blog post detailing some of these differences, Estelle

Oberholzer, owner of a chess supply shop and creator of the blog “House of Chess”, highlights

that most online chess boards are two-dimensional. This means that the recognition skills built

online often do not translate well to a physical, three-dimensional board [2]. This coordination is

needed for players to effectively maneuver their pieces under pressure given that in chess if a

piece is touched it must be used for the next move. This contrasts with online chess wherein

players can draw arrows on the board to visualize sequences of moves before they are made.

Given these differences, players who are used to online chess can find themselves dealing with a

skill-gap when it comes to traditional gameplay, especially in a tournament setting.

## Project Description

ChessConnect allows players the easy accessibility of online play, while still allowing

them to develop the skills necessary for over-the-board play. ChessConnect links seamlessly with

one of the largest internet chess servers, Lichess.org, and allows users to play with any type of

opponent on the site including: random players, specific friends, or chess computers. This

provides users with the flexibility of online chess while building good habits for over-the-board

play. Using an existing online chess service also reduces the higher cost associated with integrated chess computers and proprietary solutions. ChessConnect further enhances the

traditional chess experience by automatically translating the online opponent’s moves to the

physical board using an internal electromagnet. By interfacing with magnets internal to the

pieces, ChessConnect removes the burden of manually updating the pieces seemingly by magic

and maintains a traditional look and feel. After the initial setup, ChessConnect only needs to be

connected to power and does not require the use of an external application on a personal

computer to function. Once the device is connected to Wi-Fi and linked to the user’s Lichess.org

account, ChessConnect operates using only the physical buttons to start a game. The LCD screen

prompts the user to select a game-mode and time controls, as well as shows the chess clock once

a match starts. During a game, the screen also shows the destination of the opponent’s piece

while it is being moved and gives warnings and corrections for illegal moves accompanied by an

audible alert. An overall design sketch of ChessConnect is shown in Figure 1.

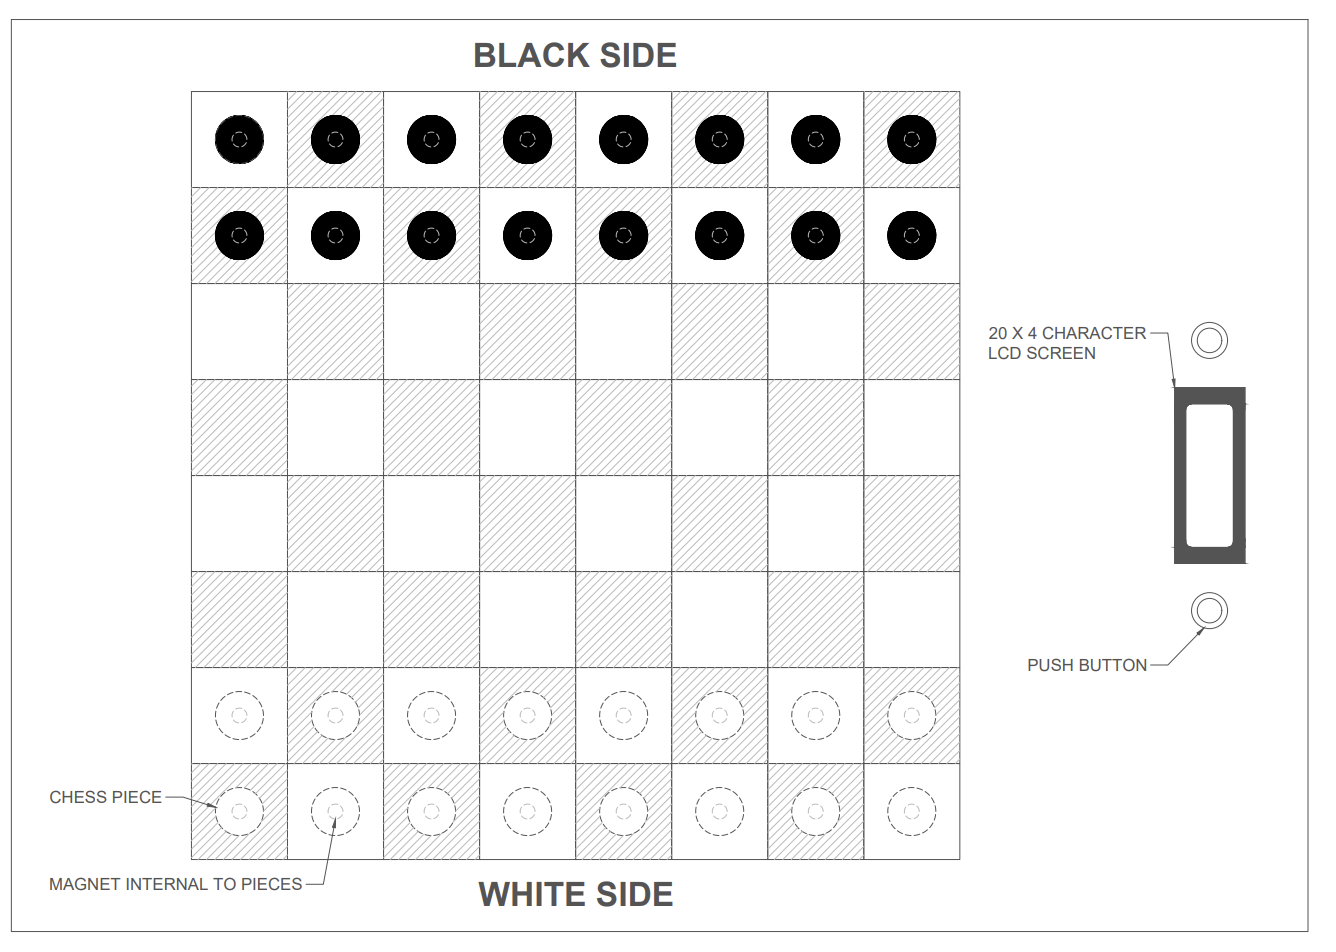
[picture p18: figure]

Fig. 1. Overall sketch of ChessConnect.

Throughout a chess game, ChessConnect manages the movement of pieces, verifies their

positioning, and communicates with the online game server. In doing so, the board allows for

seamless connectivity and gameplay with online opponents. A flowchart describing how

ChessConnect functions during a chess game is shown below in Figure 2.

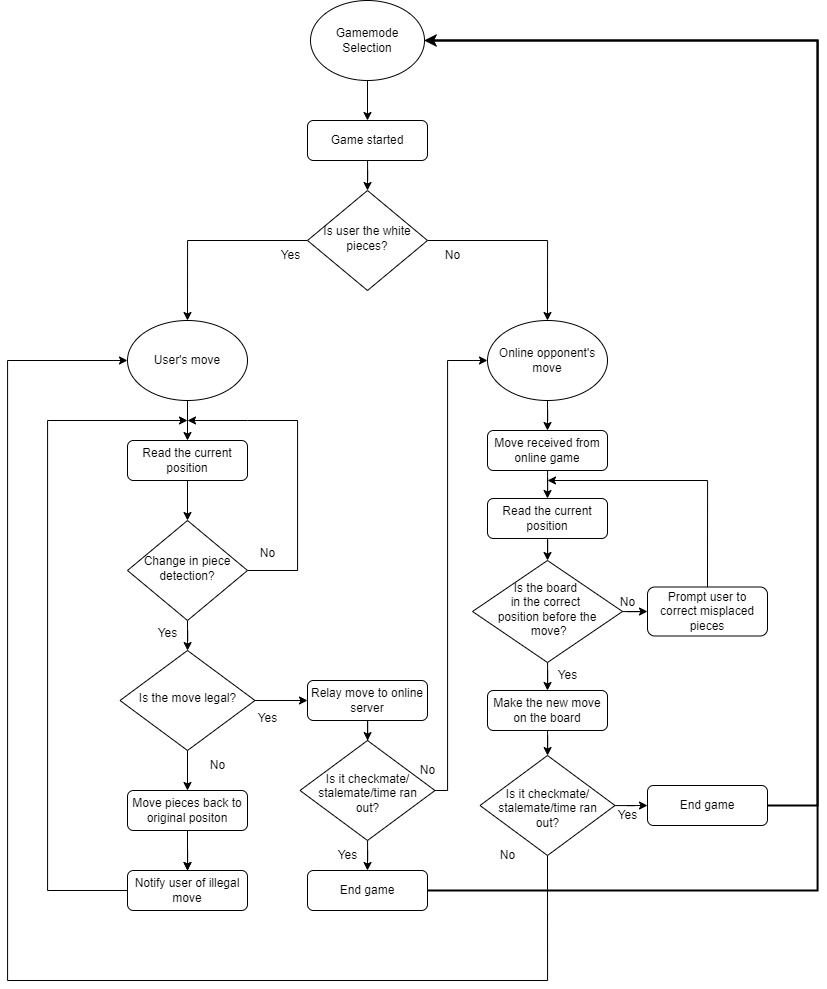
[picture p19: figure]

Fig. 2. Flowchart of program control during a chess game.

## Functional Requirements

The functional requirements listed below are important qualities that the ChessConnect

must possess in order meet the user’s expectations for the product and achieve the desired

behavior. These requirements were then incorporated into the House of Quality (HoQ) to

highlight the areas that consumers would value most and to visualize their relative importance to

one another as shown in Figure 3. The list below highlights each of the requirements and gives a

brief explanation of each:

- Affordability: how much ChessConnect will cost. If the product is outside of the average

customer’s price range, it fails at being accessible to a wide audience. Ideally,

ChessConnect will have ample features compared to competitors while maintaining a

viable price point.

- Playable Area: the amount of space allotted for the chessboard on ChessConnect. The

board should remain large enough to easily access pieces and visualize the game while

also being small enough to allow for portability and fit the standard for chessboard

dimensions.

- Size of Pieces: the size of the chess pieces to be used on the board. The sizing of pieces is

an important requirement for those who wish to practice for tournament play. Pieces must

follow guidelines so that users practicing with ChessConnect can easily transition their

muscle memory to a tournament. Furthermore, larger chess pieces are typically viewed as

being of higher quality and offer a better experience. To offer the best end-user

experience, the size of each piece should be as close to chess tournament standards as

possible.

- Build Quality: the overall quality of the ChessConnect device and experience. The

materials should be sturdy enough to withstand the movement of the internal XY rail

system for prolonged use and the aesthetics should be of a relatively high quality while

maintaining affordability. The gameplay experience should be as seamless as possible,

minimizing any errors or connectivity issues.

- Piece Movement Speed: the speed at which automatically moved pieces will travel. If a

piece is moved too quickly, it may lead to less precise movement and knock over other pieces. However, if a piece is moved too slowly, it can become an inconvenience for the

user and may impact their time remaining to make their next move.

- Ease of Use: how comprehensive the user interaction with the device must be. The

startup sequence of ChessConnect must be intuitive, allowing users to quickly begin

playing. It is necessary to develop the UI so that users can effectively navigate all

features of the device while minimizing the amount of selection screens and input

required to do so. Along with this, the display on the board must be informative,

responsive, and straightforward at all times.

- Gameplay Options: how many gameplay modes are available. These gameplay options

include different time controls, varying difficulties for online bots and opponents, and

even the capability to play a normal game over-the-board. For a customer, having as

many gameplay options as possible will make for the best user experience. Minimizing

these choices can lead to less customer satisfaction and less functionality.

## Engineering Specifications

After functional requirements were determined, engineering specifications were created

as a means to measure each functional requirement. These specifications along with their

relationships to the functional requirements are detailed in the middle of the HoQ as shown in

Figure 3. The positive (+) and negative (-) correlations between each of the engineering

specifications are detailed in the roof of the HoQ. The engineering specifications have two

values: a design target and a design threshold. The design target is the desired value for a given

engineering specification and is deemed the best-case scenario in achieving the desired

functionality. The design threshold is the value determined to be the minimum acceptable target

for a given specification to fulfill the desired functionality. The design targets and thresholds are

shown at the bottom of the HoQ as well as in Table 1. The engineering specifications, along with

a brief explanation of their associated design targets and thresholds, are outlined below:

- Manufactured Cost: the total cost in USD of the raw components needed to create

ChessConnect. The cost target was determined based on the components that have been

selected to create the device. The current total of these components is roughly $300

before taxes, so the target for manufactured costs has been set at $350. ChessConnect

aims to be a more budget-friendly option compared to its competitors, therefore determining a reasonable threshold for the manufactured cost is critical. Most of the

electronic chess boards on the market are priced similarly to the target of $350, but they

also lack the automatic movement functionality that ChessConnect provides.

Additionally, the only electronic chess board currently on the consumer market that

matches ChessConnect’s functionality, Square Off’s Miko Chess Grand, retails for $550

[3]. Given that this product is ChessConnect’s main competitor in terms of features, the

cost threshold was set at $500 to maintain a cheaper cost than the competition. This

threshold adds 43% to the manufactured cost target which will account for any costs that

may arise due to the addition of components if needed.

- Size of Device: how large ChessConnect will be dimensionally in inches (Length x Width

x Height). The device must be small enough to be portable and convenient for the end

user while being large enough to support a sizeable playable area and allow for the

internal electronics. In order to have space for the rail system, LCD screen, push buttons,

and other components, the design target is 27in x 19in x 3.5in. This will allow for an

extra 11 inches of length and 3 inches of width outside the playable area (16in x 16in).

This extra area will house internal components, allow for XY rail mobility, and be used

for the LCD display. Along with this, the height of 3.5 inches will provide enough

vertical clearance for the rail system and reed switches to be housed inside the board. The

design threshold at 32 in x 24in x 4.5in provides increased tolerance for mounting

components and the XY rail system.

- Automatic Piece Move Time: the time, in seconds, it takes from when ChessConnect

receives the opponent’s move until the pieces are repositioned on the board. Since chess

has a large variance in move types, it can be challenging to find a standard for measuring

the time it takes for the device to reflect the virtual opponent’s move. For example,

moving a pawn one square takes much less time than taking a piece on the other side of

the board with a rook. To create a standard for measuring this process, a specific move

has been determined as a basis for measuring the time it takes to receive the opponent’s

move, update the piece positions, and turn over control to the ChessConnect user: a pawn

taking a pawn in the center of the board. This move involves moving the taken piece

outside of the playable area and moving the opponent’s piece to the new space which is a

good middle ground between overall move time and move complexity. This move is also very common in many early game positions given that one of the core principles of

opening play is to control the center of the board using pawns. According to Chess.com’s

explorer, which displays the most common opening moves among master games, the

predominant opening moves involve moving several pawns to the center of the board [4].

This results in the very common scenario where one of these pawns captures another.

Target and threshold values were determined based on analysis of the only other

electronic chessboard that moves pieces automatically, the Miko Chess Grand [3]. Online

videos of this board were used to make an estimation for the threshold and target time.

The design target for the standard move time is 6 seconds, and the threshold is 11

seconds.

- Time to Start a Game: the number of screens required to start a new game. The design

target for this specification is 3 screens, and the threshold is 6. These values were

determined by estimating the number of necessary screens needed to get into a game with

an opponent. The board must have at least a start screen, a screen to select opponent type,

and a screen to select time control. While it is best to keep this specification to a

minimum, some features may require more options and selection screens. Therefore, the

design threshold is set to 6 screens to accommodate these potential occurrences.

- Piece Detection Errors (per 40 moves): the number of incorrectly detected pieces for

every 40 moves from the user or opponent. A piece detection error occurs whenever the

board is unable to accurately detect the piece positions when reading the user’s move or

verifying the opponent’s move. The primary scenario where errors can occur is when the

user presses the button to end their turn, but the board is unable to recognize where their

piece has moved to. This would result in the user having to reset their piece and make

their move again. The second scenario for errors occurs when verifying the piece

positions after an automatic move. ChessConnect scans the positions after every

automatic move to make sure that piece placement is correct. If pieces become

misaligned during movement from either inaccuracy or being knocked too far out of

place, the user will have to manually align the pieces until they are properly detected.

According to online database chessgames.com, the average chess game is roughly 40

moves, so this specification outlines how many detection errors are acceptable in an

average game [5]. The design target for this specification is 1 error per 40 moves, which allows for some error in piece detection while allowing for minimally interrupted

gameplay so that the user experience will be maintained. The threshold of 3 errors per 40

moves was determined in a similar fashion and is viewed as being the upper limit of

permissible errors before the user experience starts to diminish.

- Piece Scaling (King Height): the measured height in inches of the king chess piece. The

relative heights of chess pieces are scaled relative to the height of the king. Many chess

players are particular about the scaling of their pieces and may want them to be a certain

height in a chess set. The design target is 3.5 inches tall, which is approximately the

average height for the king piece in consumer chess sets. The design threshold for this

specification is 2.25 inches, which will make sure that the king and piece height is not too

small. This ensures that the pieces do not look strange or become difficult to handle.

Table 1: Functional Requirements and Engineering Specifications

Engineering Specifications • Related Functional Requirements | Units | Desired Direction | Design Target | Design Threshold
Manufactured Cost • Affordability • Playable Area • Size of Pieces • Build Quality • Piece Movement Speed | $ | ↓ | $350 | $500
Size of Device (L x W x H) • Affordability • Playable Area • Size of Pieces | Inches | ↓ | 27x19x3.5 | 32x24x4.5
Automatic Piece Move Time • Piece Movement Speed • Affordability • Playable Area • Size of Pieces • Build Quality • Gameplay Options | Seconds | ↓ | 6 | 11
Time to Start a Game • Ease of Use • Gameplay Options | Screens | ↓ | 3 | 6

Table 1 cont.

## Competition

The competition for ChessConnect includes several companies that offer similar products

aimed at bridging the gap between traditional and online chess. Some of the key competitors

include Miko Chess Grand, ChessUp, Chessnut Air +, and DGT Pegasus. These competitors,

along with where they rank in terms of functional requirements, are shown in the HoQ in

Figure 3. While these products provide the core functionality of electronic chess boards by

linking physical and online play, ChessConnect stands out in several key areas.

One of the biggest advantages that ChessConnect has over the competition is the ability

to move the opponent’s pieces automatically. All the competitors listed except for Miko

Chess Grand lack this capability. Additionally, the Miko’s price point of $550 makes it less

accessible and affordable. These competitors are also largely training focused, with emphasis

on teaching modes, analysis, and puzzles. ChessConnect focuses on reducing complexity by

providing users with a fast and straightforward solution for playing online chess games over

the board. While competitors may offer the online compatibility of ChessConnect, none of

them offer the combination of functionality, convenience, and affordability of ChessConnect.

Piece Detection Errors (per 40 moves) • Affordability • Build Quality • Piece Movement Speed • Ease of Use • Gameplay Options | # | ↓ | 1 | 3
Piece Scaling (King Height) • Affordability • Playable Area • Size of Pieces • Build Quality • Ease of Use • Piece Movement Speed | Inches | ↑ | 3.5 | 2.25

## House of Quality

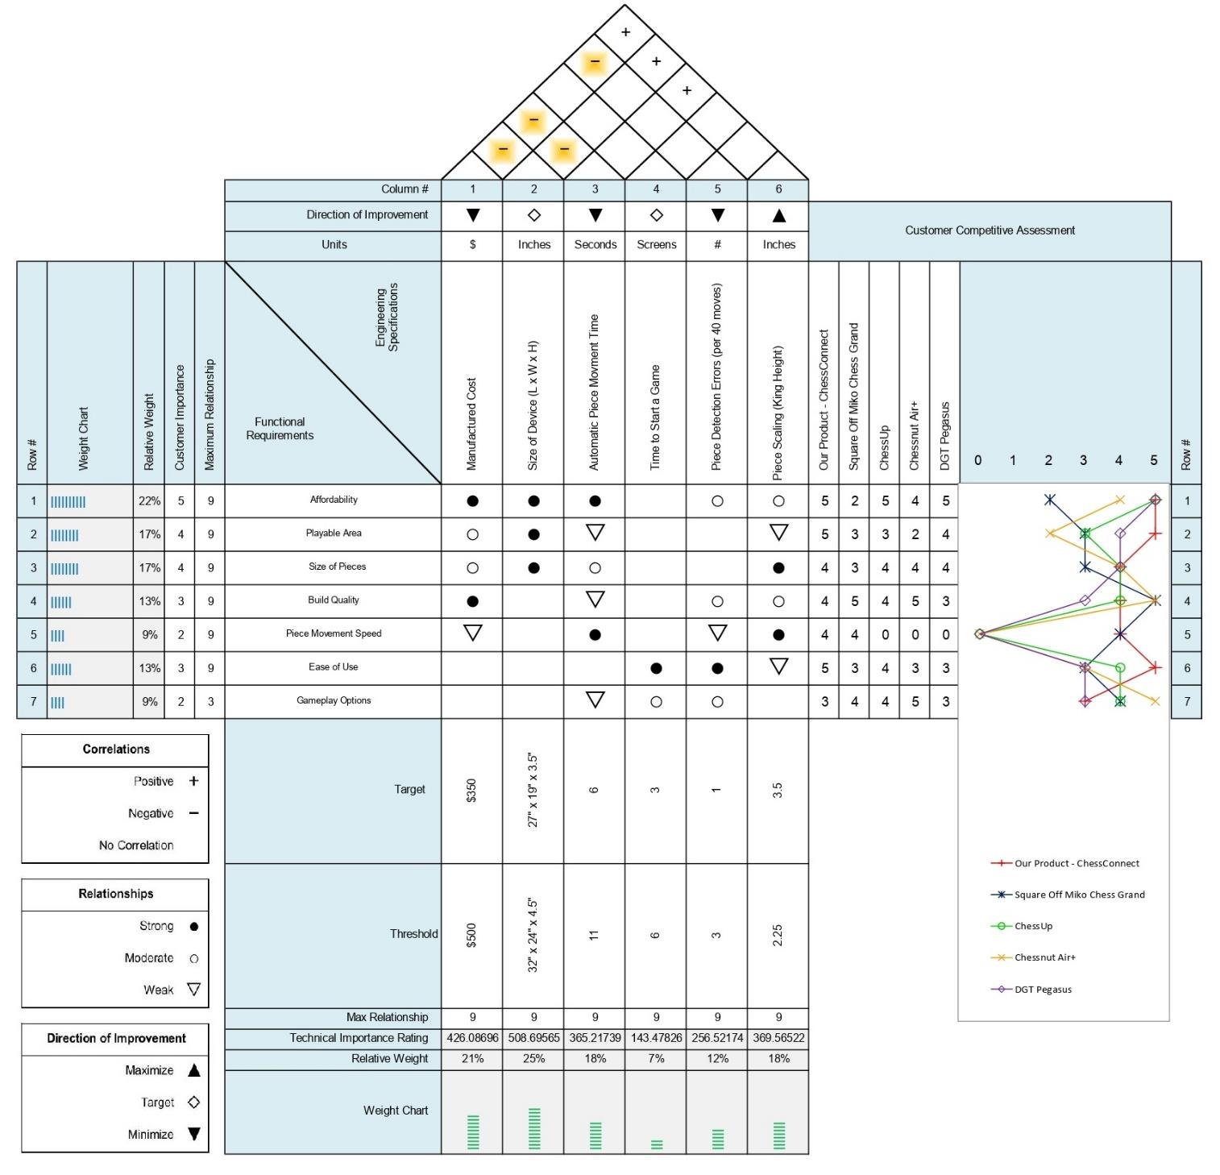
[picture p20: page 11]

Fig. 3. House of Quality

## Impact

ChessConnect aims to bridge the gap between online and over-the-board chess formats.

By merging the good habit building of over-the-board chess and the convenience of online

chess, ChessConnect creates a unique and enjoyable way for any user to play chess. In a

global context, ChessConnect enables players from different parts of the world to compete in

a physical environment, while staying connected to the online community. Economically,

ChessConnect aims to be affordable and accessible, offering a cost-effective alternative to

high-priced competitors without sacrificing quality.

The materials that make up ChessConnect are chosen to reduce its environmental impact

as much as possible. 3D printing allows for precision in material usage, reducing more waste

than traditional molding or cutting processes. Furthermore, the use of wood to construct the

overall device housing as well as other components in future versions (such as the chess

pieces) will help to make the product more recyclable. However, the use of plastics in 3D

printing raises some concerns, as they can cause harm to the environment if not properly

disposed of during the manufacturing process. The energy consumption of ChessConnect can

indirectly impact the environment, although this is extremely minimal considering the low

power of the device. The electronics inside the device also pose an environmental risk if they

are not disposed of properly at the end of the product’s life cycle. By mitigating these risks,

ChessConnect demonstrates a safe and affordable device that enhances the chess-playing

experience while fostering global connectivity and maintaining environmental responsibility.

## Safety

ChessConnect is designed to be a consumer-facing product, and therefore ensuring user

safety is extremely important. The board requires connection to external power, which

introduces risks of electrical shock and overheating. The board should not be operated in the

rain or other wet environments to reduce the risk of electronic malfunctions. The continuous

operation of the electromagnet, motors, and other electronic components also poses the risk

of overheating. Although it is unlikely, the force of a magnetically moved piece being

launched off of the board could potentially cause bodily harm. To reduce this risk, the

movement of pieces will be calibrated such that these moving parts are not inherently dangerous. Typical interaction with chess pieces poses no harm, but since the pieces are

small, they can act as a choking hazard and could cause pain if stepped on. Therefore, users

are advised not to use the chess pieces outside of their intended purpose. Along with risks

associated with pieces, the device itself can be hazardous to users. The device can cause

bodily harm if a user were to drop the device onto themselves or if they trip and fall over the

power cord. Overall, ChessConnect is an extremely safe product when used in the proper

context.

## Conclusion

ChessConnect offers a unique solution that blends the strengths of both online and over-

the-board chess formats; creating a product that enhances the player’s experience through

accessibility, affordability, and ease of use. ChessConnect focuses on maximizing

functionality and consumer needs while still standing out in its market. It not only fosters

global connectivity but also builds good chess-playing habits. By addressing safety concerns

and acknowledging environmental impact, ChessConnect balances innovation with

responsibility. As a result, ChessConnect stands out as a modern, functional, and convenient

tool for chess enthusiasts and new players alike.

## References

[1] “Lichess.org Open Database,” Lichess.org, database.lichess.org
(accessed Aug. 29, 2024).
[2] E. Allebest, “Interesting chess data: Time controls and game results,” Chess.com, www.chess.com/article/view/interesting-chess-data-time-controls-and-game-results (accessed Aug. 29, 2024).
[3] “Miko Chess Grand - Worlds smartest chessboard with an AI spin,” Miko. https://miko.ai/products/miko-chess-grand (accessed Oct. 27, 2024).
[4] “Chess Opening Explorer & Database,” Chess.com. https://www.chess.com/explorer (accessed Oct. 28, 2024).
[5] “Chess statistics,” chessgames.com, www.chessgames.com/chessstats.html (accessed Oct. 10, 2024).

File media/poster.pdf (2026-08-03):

# ChessConnect – Classic Chess, Modern Connectivity

# Students: Joseph Denk, Brendan Jugan Advisor: Dr. Laura Wieserman University of Pittsburgh at Johnstown

### Abstract

### Problem

### Important Components

Chess has evolved with the rise of online play, but this shift introduces compromises. Online distractions, shorter time controls, and the lack of physical interaction impact the development of good habits for over-the-board chess. However, finding local opponents of similar skill can be inconvenient, making online play the more accessible option despite its drawbacks. Many players struggle with translating online skills to physical games due to differences in coordination and board visualization.

ChessConnect bridges the gap between online and traditional formats, giving users the convenience of online play while maintaining the benefits of traditional chess. By integrating seamlessly with Lichess.org, users will be able to start a game against anybody in the world while playing the game on a physical board. Whenever a user makes a move on the board, it will automatically be interpreted and sent to the online game. Similarly, when the online opponent makes a move online, their piece will be automatically moved to its new position on the board using the internal gantry. By eliminating manual move translation and allowing for the convenience of online connectivity, ChessConnect offers a seamless and immersive chess experience.

Arduino Uno:
The Arduino Uno R4 WiFi microcontroller is the “brains” of ChessConnect. It is used to acquire data from the various inputs, interpret the user’s chess moves, and connect to and facilitate online gameplay.
LCD Display:
The LCD will display the UI needed to setup a game and transition to show the in-game chess clock once the game has started. If an error in piece positions occurs, the LCD screen will also be used to inform the user how to resolve the error.
Reed Switches:
Reed switches are used to track the positions of the pieces during a game. These switches are located under every square of the board which allows them to interact with the magnets in the base of each piece.
Electromagnet:
The electromagnet is used in the XY rail system to control piece movement. When the online opponent’s move is received, the magnet will be positioned beneath the piece, turn on, carry the piece to its new position, and turn off. Motors:
Two motors are used to facilitate the movement of the electromagnet mounted on the XY gantry. This allows the ChessConnect to maneuver the game pieces from within the board.

ChessConnect is a new and exciting chess experience that combines the iconic gameplay of traditional chess with online connectivity in a standalone package. ChessConnect allows users to play over-the-board games against an online opponent by interfacing with the chess website Lichess.org. Using magnetic pieces and an internal cartesian gantry, the online opponents’ moves are automatically relayed onto the chess board in real time while preserving the traditional look and feel that serious players expect. Additionally, the ChessConnect user’s moves are automatically detected and sent to the online game using magnetic detection switches, allowing for easy, seamless connectivity between the online platform and the user. All of this is done in a single, minimalistic device which, once linked to a Lichess.org account and connected to WiFi, requires no external devices and operates with only two buttons and an LCD screen. Using this technology, ChessConnect bridges the gap between traditional skill and modern convenience while removing the limitations of both formats.

### Hardware Block Diagram

### ChessConnect (Internal & External View)

### Solution

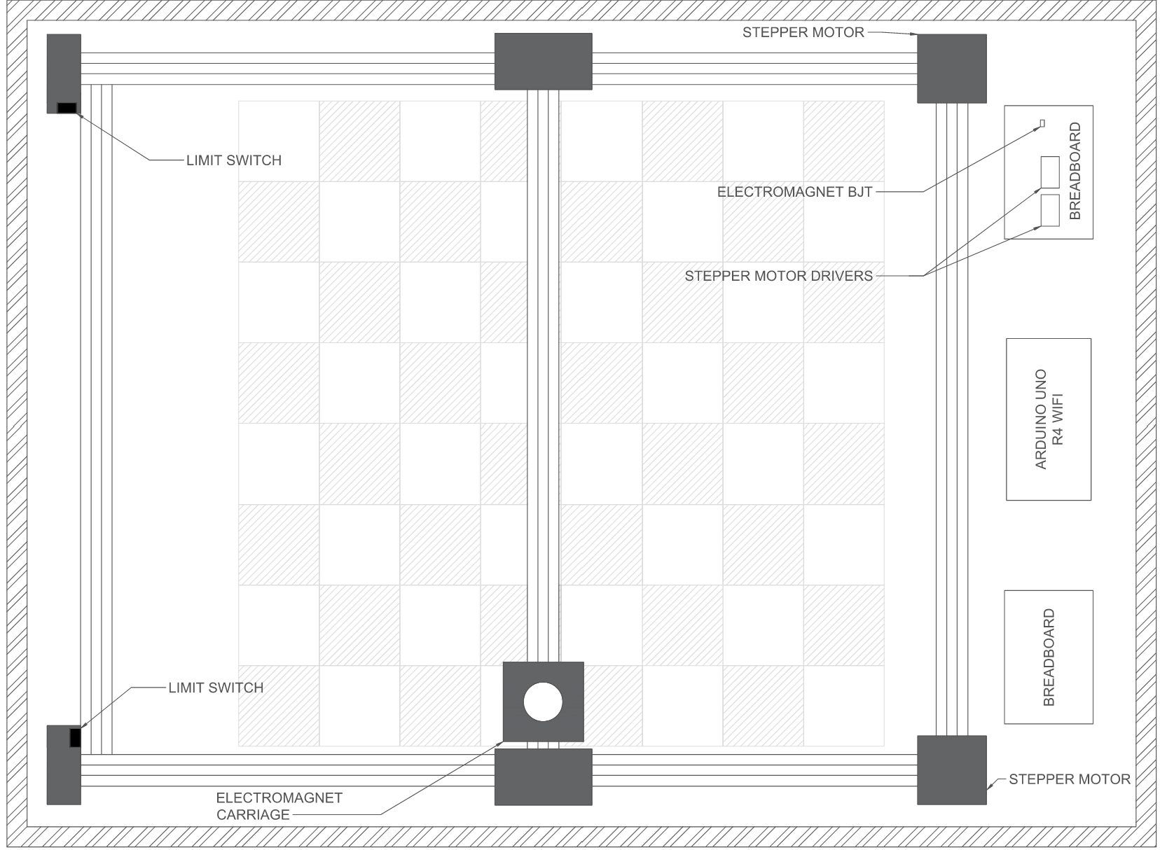
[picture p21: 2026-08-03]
media/schematic-internal.png

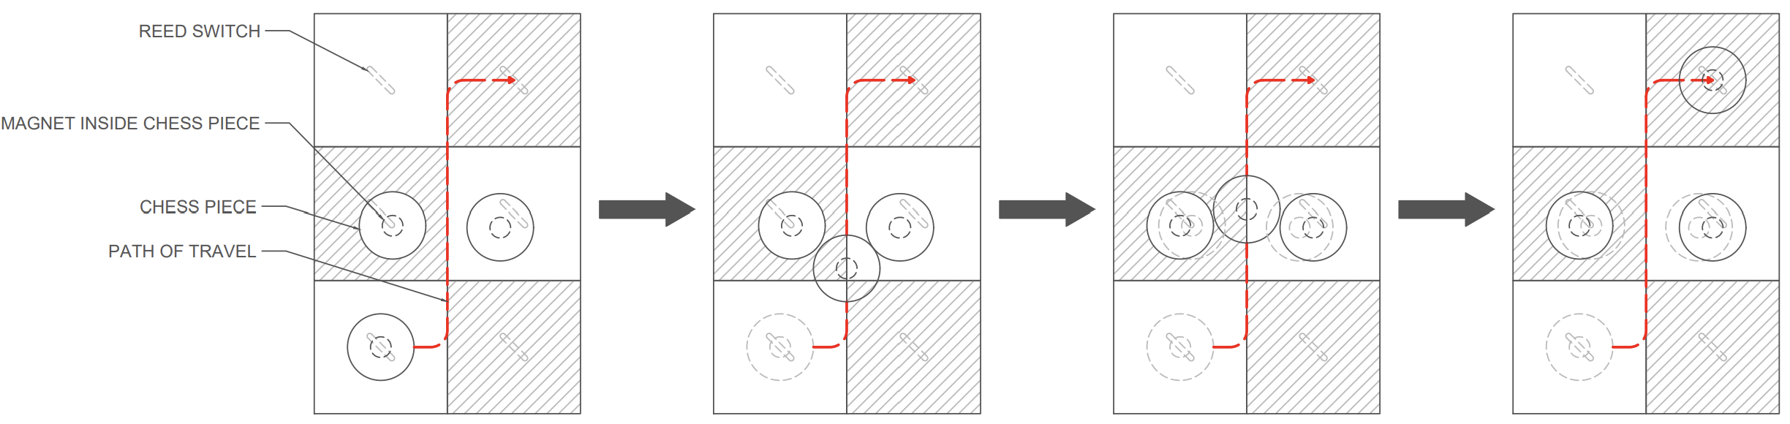
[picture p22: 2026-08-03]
media/schematic-piece-movement.png

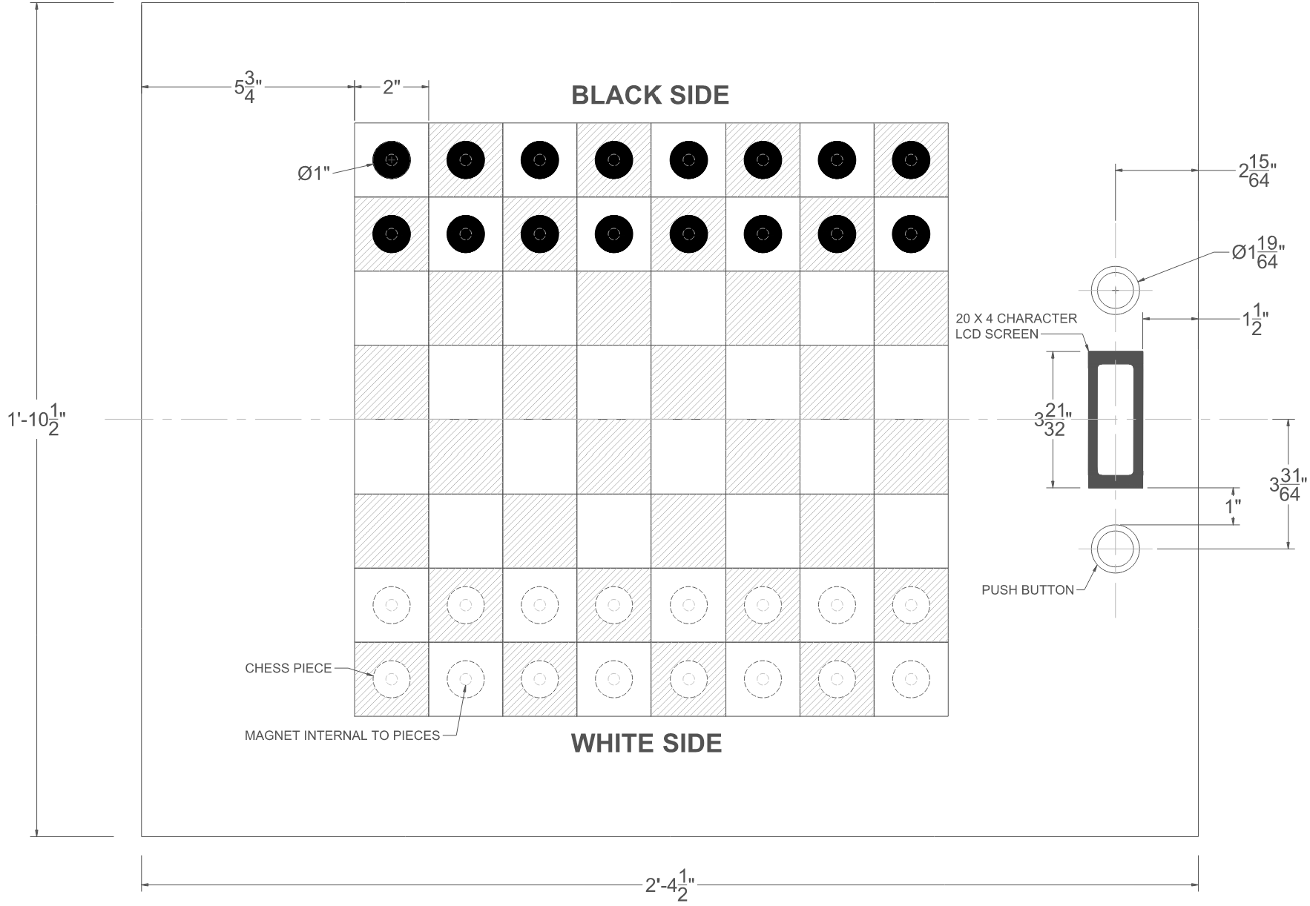
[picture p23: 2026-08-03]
media/schematic-overall.png

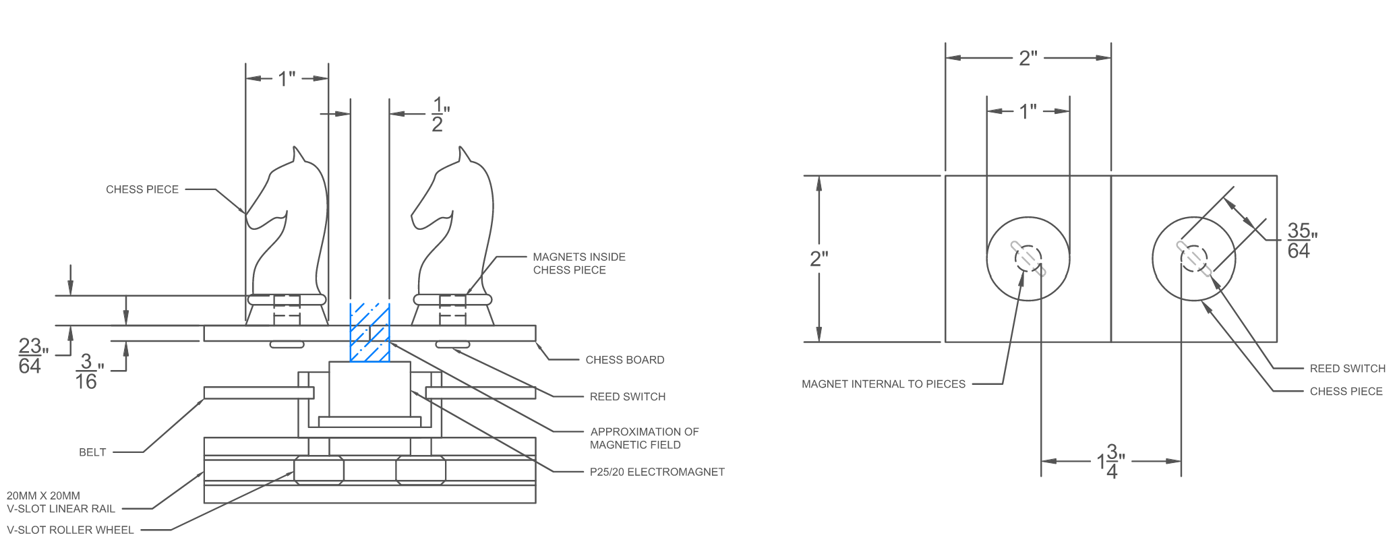
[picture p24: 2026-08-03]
media/schematic-englarged.png

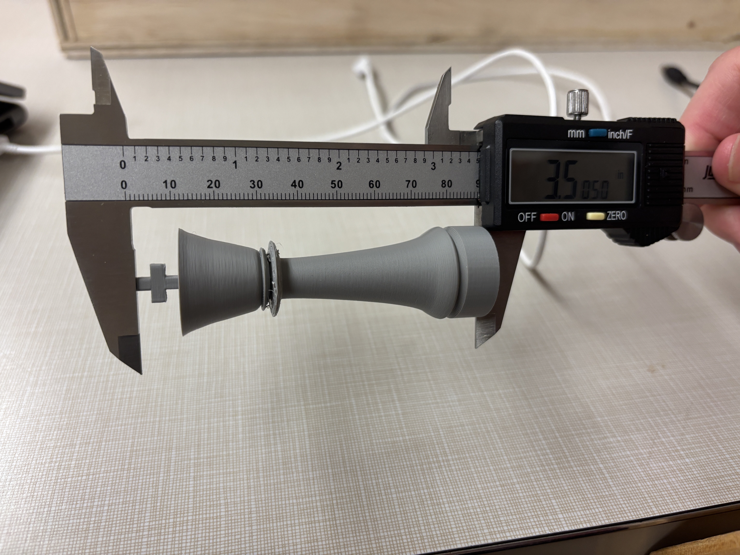
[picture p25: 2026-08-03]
media/king-piece-height.jpg

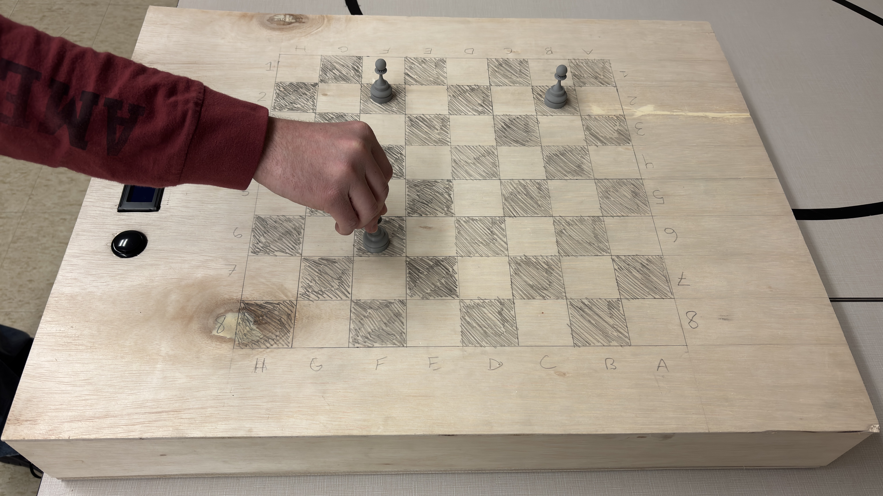
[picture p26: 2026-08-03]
media/external-view.jpg

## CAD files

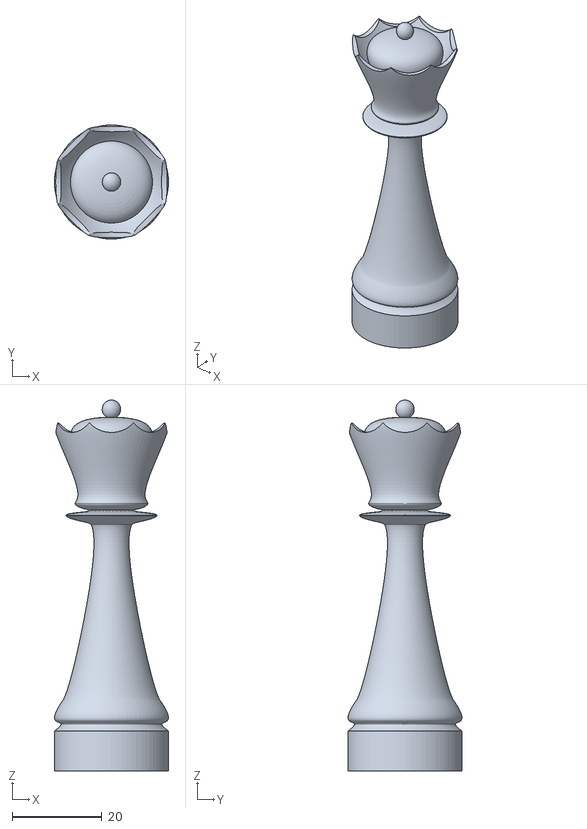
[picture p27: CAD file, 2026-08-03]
hardware/models/stl/queen.stl
25.4 x 25.4 x 82.6

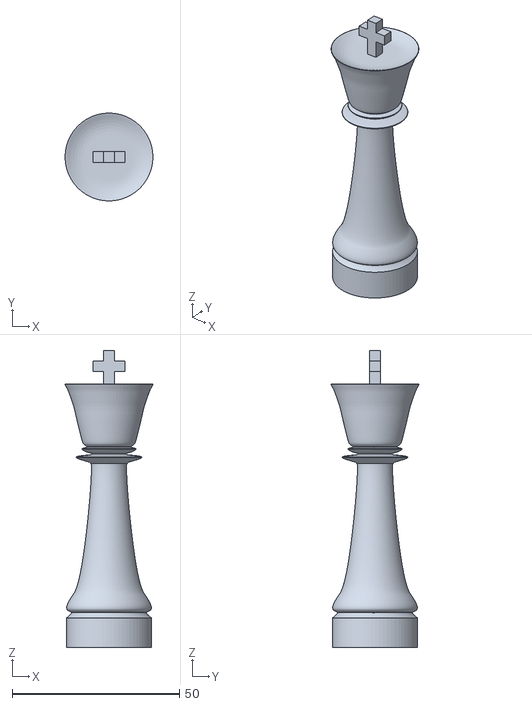
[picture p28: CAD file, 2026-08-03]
hardware/models/stl/king.stl
26.3 x 26.3 x 88.9

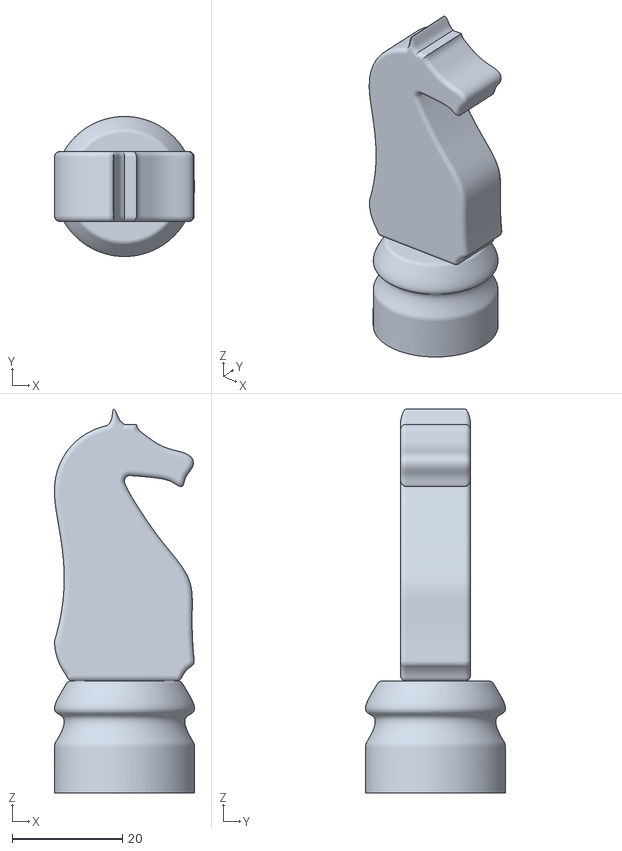
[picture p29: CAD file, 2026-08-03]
hardware/models/stl/knight.stl
25.4 x 25.4 x 69.6

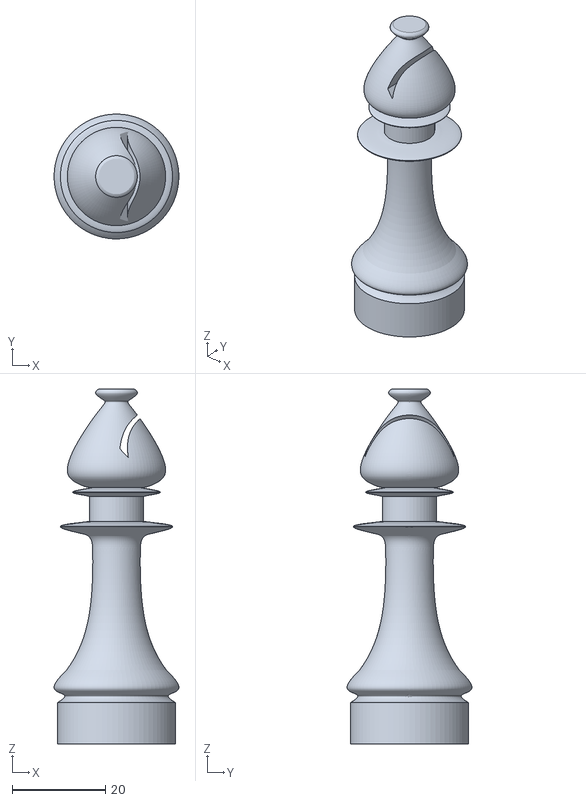
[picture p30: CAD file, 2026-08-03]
hardware/models/stl/bishop.stl
26.8 x 26.8 x 76.2

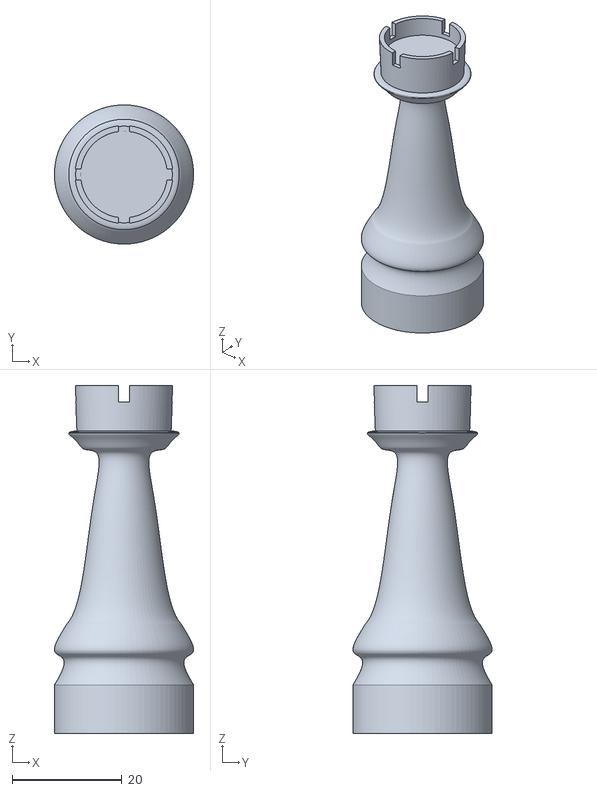
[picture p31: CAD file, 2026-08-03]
hardware/models/stl/rook.stl
25.4 x 25.4 x 63.5

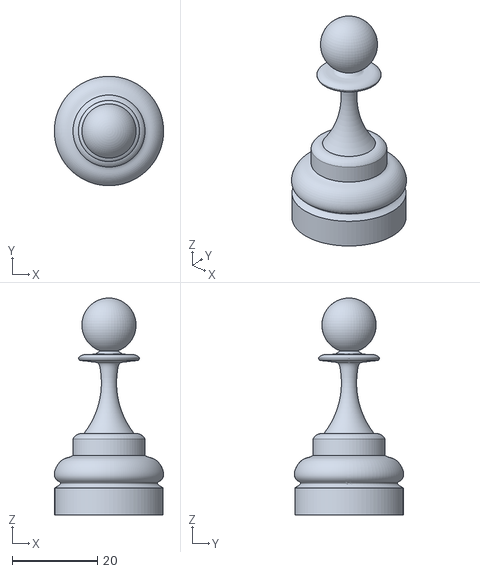
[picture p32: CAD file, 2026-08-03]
hardware/models/stl/pawn.stl
25.6 x 25.6 x 50.8

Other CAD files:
hardware/models/fusion/bishop.f3d
hardware/models/fusion/king.f3d
hardware/models/fusion/knight.f3d
hardware/models/fusion/pawn.f3d
hardware/models/fusion/queek.f3d
hardware/models/fusion/rook.f3d

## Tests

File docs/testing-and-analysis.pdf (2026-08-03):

## CoE 1199 Senior Project

## ChessConnect

## Final Testing and Analysis

## Joseph Denk and Brendan Jugan

## Department of Electrical and Computer Engineering


## Testing Methodology

During the creation of ChessConnect, three phases of testing were used to ensure

complete functionality: subsystem, integration, and final device. First, testing was conducted on

each isolated subsystem to ensure that it operated as intended. The team then began testing

subsystems that had been integrated together to perform complex functions used in the final

device. Lastly, holistic testing on the completed device was used to confirm that full operation

was achieved, refine the user experience, and detect any underlying bugs and issues.

## Subsystem Testing

The core subsystems that makeup ChessConnect’s architecture were constructed

independently to speed up development time and act as building blocks when creating the higher

functions of ChessConnect.

The internal gantry and control circuit were initially tested using a button setup for

manual control at various speeds. Using four buttons for the cardinal directions and a fifth for

activating the electromagnet, the project group was able to observe the maximum speeds and

accuracy of movement as well as verify that electromagnet could maintain its control and

strength throughout. This testing also revealed alignment issues and the fact that the rail system

moved at half speed during diagonal movement which was later accounted for in software.

When creating the piece detection circuit, the group first needed to verify that the Reed

switches could effectively be activated through the wooden material. This was accomplished via

a basic circuit that used one of the magnetic switches to activate an LED. This gave the group

vital information about the radius and consistency of activation and confirmed its viability as a

solution. Once the Reed switches were mounted and wired into the four multiplexers and microcontroller, test code was developed to scan all the switches to detect their open/closed state.

The group confirmed individually that all 64 Reed switches could be triggered and detected in

software using the designed system. This testing not only served as the basis for future move

detection code but also ensured that all soldered connections were reliable and that pieces would

not accidentally trigger neighboring sensors.

Lastly, API communication was tested by using small code segments as proof-of-

concepts for the various communication requirements. The group first ensured that a basic TCP

connection to Lichess.org could be established over WiFi. Throughout this process, the project

group discovered early on that the original microcontroller and external WiFi module was

incapable of connecting to the Lichess API and was able to quickly resolve this by choosing a

different microcontroller. After a successful connection was established, the focus shifted

towards obtaining and displaying a stream of an active game using API calls. This allowed the

device to obtain and later interpret the live response of moves in an ongoing game.

## Integration Testing

After subsystem testing was completed, integration testing was conducted to ensure that

the subsystems interacted properly with each other to accomplish a larger task.

To test autonomous piece movement, the gantry was secured inside the enclosure and

used to verify that moves from the online game stream were being correctly recognized and

translated into physical movement. This test was also used to verify multiple aspects regarding

the electromagnet and movement of pieces. During testing, the project group determined that the

strength of the magnet was insufficient for moving pieces from within the chassis and purchased

a new electromagnet with sufficient strength. It also revealed that diagonal movement was

slightly inaccurate and could lead to a loss in calibration when repeatedly used. In response to this, periodic recalibration was implemented based on the number of diagonal moves made

during a game, resulting in better overall accuracy.

Move detection was tested by repeatedly making moves with the physical chess pieces

and printing the source and destination squares to the LCD screen. This allowed the team to

quickly verify both the functionality and consistency of the piece detection system. Additionally,

the serial monitor was used to print the entire state of the board as pieces were moved to verify

that the software scheme for internally storing the local game state of the device was functioning

consistently. This revealed issues with the strength of the piece magnets in relation to Reed

switches, oftentimes leading to very inconsistent detection. To remedy this issue, more tests were

conducted on different magnet solutions to determine which provided the most consistent

detection. This result was a design change from a single 8mm diameter magnet to two of these

magnets side by side. This increased the radius of detection and provided a push and pull

configuration which was much more consistent, however it also made movement very inaccurate

because the point of magnetism on the pieces was no longer in the center. Ultimately, a design of

three 8mm magnets stacked on top of each other offered the best detection while also allowing

consistent piece movement.

This code was then combined with the API communication to test the software’s ability

to correctly format the various chess moves to be received by Lichess.org. This allowed the

project team to learn how to send the various gameplay functions and inputs as well as handle

edge case responses from the server.

## Final Device Testing

Once the device construction and software were finalized, complete device testing was

conducted to ensure that ChessConnect operated as designed.

Automatic piece movement was verified using active games on a personal Lichess.org

account. This gave the project team manual control over what moves were received and made it

easy to test special moves, edge cases, and movement time. Movement speeds were adjusted to

optimize between fast operation and accurate piece handling and ensure that the automatic piece

move time engineering specification was met.

Local gameplay on ChessConnect was used to confirm that all cases of legal and illegal

moves could be detected and handled as well as measure the number of detection errors. Several

complete chess games were played by third parties to accurately track instances of faulty

detection due to inconsistent triggering. This also gave the team the opportunity to collect

insights into potential improvements in usability. The measured number of piece detection errors

was slightly higher that the threshold set during the design phase, an issue likely caused by the

combination of board material and lower quality of the Reed switches. This combined with the

user feedback led to the implementation of extra controls to correct and redo errors in move

detection so that games can persist through these issues.

These tests were also used to monitor ChessConnect’s internal record of the ongoing

game over the microcontroller serial monitor and ensure that synchronization was being

maintained with the online game even during special piece moves and edge cases. This allowed

the team to fix several code bugs which would have otherwise gone unnoticed during the team’s

own preliminary testing.

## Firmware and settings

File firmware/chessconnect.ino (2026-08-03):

//Joseph Denk, Brendan Jugan
//ChessConnect - Source Code
//April 28, 2025


//include necessary libraries

//Credentials (WiFi + Lichess API) - loaded from secrets.h (not tracked in git)
#include "secrets.h"
//wifi libraries
#include "WiFiS3.h"
#include "WiFiSSLClient.h"
#include "IPAddress.h"
//json parsing library
#include <ArduinoJson.h>
#include <Wire.h>
//lcd 
#include <LiquidCrystal_I2C.h>
LiquidCrystal_I2C lcd(0x27, 20, 4);
//stepper motor
#include <AccelStepper.h>
int once = 0;
//piece structure, used to keep board state internally, keeps piece type and color
struct Piece {
  char type;
  int color;
};
//game state
String state;
//illegal move var
int wrong = 0;
//electromagnet state
int emState = 0;
//to read responses
String resp;
//tracking board states w/ piece structs
Piece board[8][8];
Piece lastBoard[8][8];

String lastBoardMove="";
//to store reed switch states 
int squares[8][8];
int lastsquares[8][8];

//for promotions
int promotion = 0;
char promotionPiece = ' ';
// Define pin connections for steppers
const int dirPin1 = 13;
const int stepPin1 = 12;
const int dirPin2 = 11;
const int stepPin2 = 10;
//game info
String gameID = "";
String userColor = "";
//user color var
int userColorInt;
//calibration
int calibrate = 0;
// Define motor interface type
#define motorInterfaceType 1
int diagonalNum = 1;

// Creates an instance of steppers
AccelStepper stepperLeft(motorInterfaceType, stepPin1, dirPin1);
AccelStepper stepperRight(motorInterfaceType, stepPin2, dirPin2);
//defines steps to go for a square for - file movement, rank movement, diagonal movement
int stepsrank = 260;
int stepsfile = 260;
int stepsdiag = 530;
//limit switch states
int limitState1 = 0;
int limitState2 = 0;
//if user's move
int userMove;
//MUX pins
#define MUX0 4
#define MUX1 5
#define MUX2 6
#define MUX3 7
#define select0 A0
#define select1 A1
#define select2 A2
#define select3 A3
//used in move detection to find when a piece is picked up, to and from squares
int fromX = -1, fromY = -1, toX = -1, toY = -1;
String from = "";
String to = "";
String moveMade = "";
String lastSquare = "";
String id;
//opponent color
int otherColor = 0;
//wifi info
char ssid[]  = SECRET_WIFI_SSID;
char pass[]  = SECRET_WIFI_PASS;
//Lichess API key
char token[] = SECRET_LICHESS_TOKEN;
int status = WL_IDLE_STATUS;
char server[] = "lichess.org";  // name address for Lichess
int i = 0;
//gameStatus
String gameStatus = "";
String move;
String lastMove = "";
//initialize wifi client
WiFiSSLClient client;
//game started, UI variables for game selection, friend selection, time selection
int gameStarted = 0;
int gamemodeIndex = 0;
int timeIndex = 0;
String gamemodes[] = { "Friends", "Bot" };
String times[] = { "Unlimited", "180+30", "60+20", "30+20", "Back" };
String friends[] = { "brzzzzzzzzzzzzzzzz", "ChessConnect2025", "JOEDENK", "Back" };
int friendIndex = 0;
int selectingGamemode = 0;
int selectingFriends = 0;
int selectingTime = 0;
int onetime1 = 0, onetime2 = 0, onetime3 = 0;
//END VARIABLE DECLARATION

void initializeChessBoard() { //initialize board with pieces and colors
  for (int row = 0; row < 8; row++) {
    for (int col = 0; col < 8; col++) {
      board[row][col].type = ' ';
      board[row][col].color = 0;
    }
  }

  // Set black major pieces (row 0)
  char majorPieces[8] = { 'R', 'N', 'B', 'Q', 'K', 'B', 'N', 'R' };
  for (int col = 0; col < 8; col++) {
    board[0][col].type = majorPieces[col];
    board[0][col].color = 3;
  }

  // Set black pawns (row 1)
  for (int col = 0; col < 8; col++) {
    board[1][col].type = 'P';
    board[1][col].color = 3;
  }

  // Set white pawns (row 6)
  for (int col = 0; col < 8; col++) {
    board[6][col].type = 'P';
    board[6][col].color = 2;
  }

  // Set white major pieces (row 7)
  for (int col = 0; col < 8; col++) {
    board[7][col].type = majorPieces[col];
    board[7][col].color = 2;
  }
  for (int i = 0; i < 8; i++) {
    for (int j = 0; j < 8; j++) {
      lastBoard[i][j] = board[i][j];
    }
  }
} //end initializeChessBoard

void copyBoard(int revert) { //copy board state to lastboard
//revert var used to revert if there is an illegal move
//that will take it back to the lastboard state

//legal move, go to next board state
  if (revert == 0) {
    for (int i = 0; i < 8; i++) {
      for (int j = 0; j < 8; j++) {
        lastBoard[i][j] = board[i][j];
      }
    }
  } 
  //revert board state
  else {
    for (int i = 0; i < 8; i++) {
      for (int j = 0; j < 8; j++) {
        board[i][j] = lastBoard[i][j];
      }
    }
  }
} //end copyBoard



void moveFile(double x, int on) { 
  //move a certain number of squares -> x
  //file movement right: positive x, left: negative x
  //int on determines whether electromagnet is to be on or off during movement

  //if em currently not on, and to be turned on, turn on em
  if (on && emState == 0) {
    emOn();
  }
  //if em currently on, and to be turned off, turn off em
  if (on == 0 && emState == 1) emOff();

//steps to move based on one square movement of a file
  double stepsToMove = x * stepsfile;

  //move steppers to position
  stepperLeft.move(-stepsToMove);
  stepperRight.move(-stepsToMove);

  while (stepperLeft.distanceToGo() != 0 || stepperRight.distanceToGo() != 0) {
    stepperLeft.run();
    stepperRight.run();
  }

}//end moveFile



void moveRank(double x, int on) {
  //move a certain number of squares -> x
  //rank movement up: positive x, down: negative x
  //int on determines whether electromagnet is to be on or off during movement

  //if em currently not on, and to be turned on, turn on em
  if (on && emState == 0) {
    emOn();
  }
  //if em currently on, and to be turned off, turn off em
  if (on == 0 && emState == 1) emOff();
  //steps to move based on one square movement of a rank
  double stepsToMove = stepsrank * x;
  //move steppers to position
  stepperLeft.move(stepsToMove);
  stepperRight.move(-stepsToMove);

  while (stepperLeft.distanceToGo() != 0 || stepperRight.distanceToGo() != 0) {
    stepperLeft.run();
    stepperRight.run();
  }


  
}//end moveRank

void moveDiag(double x, int on) {
  //move a certain number of squares -> x
  //diagonal movement
  //int on determines whether electromagnet is to be on or off during movement
  //up right = negative
  //down left = positive

  //electromagnet control
  if (on && emState == 0) {
    emOn();
  }
  if (on == 0 && emState == 1) emOff();

  double stepsToMove = stepsdiag * x;
  stepperRight.move(stepsToMove);

  while (stepperRight.distanceToGo() != 0) {
    stepperRight.run();
    stepperLeft.stop();
  }

  diagonalNum++;
  //diagonalnum = number of diagonal moves made
  //every few moves, will recalibrate
}//end moveDiag

void moveDiag2(double x, int on) {
  //down right = negative
  //up left= positive

  if (on && emState == 0) {
    emOn();
  }
  if (on == 0 && emState == 1) emOff();
  double stepsToMove = stepsdiag * x;
  stepperLeft.move(stepsToMove);

  while (stepperLeft.distanceToGo() != 0) {
    stepperLeft.run();
    stepperRight.stop();
  }
  diagonalNum++;
}//end moveDiag2



void moveDiag2forCalibration(double x, int on) {
  //diagonal movement used for calibration purposes
  //down right = negative
  //up lef= positive

  if (on) {
    digitalWrite(9, HIGH);
    delay(1000);
  }
  double stepsToMove = 520 * -x;
  stepperLeft.move(stepsToMove);

  while (stepperLeft.distanceToGo() != 0) {
    stepperLeft.run();
  }


  emOff();
}//end moveDiag2forCalibration



void runCalibration() {

  //calibration function for electromagnet

  //read limit switches
  int limitState1 = digitalRead(2);
  int limitState2 = digitalRead(3);
  //while first limit switch not hit
  while (limitState1 == HIGH) {
    //keep reading and moving towards it until hit
    limitState1 = digitalRead(2);
    stepperLeft.setSpeed(-1000);

    stepperRight.setSpeed(1000);
    stepperLeft.runSpeed();
    stepperRight.runSpeed();
  }
  //stop 
  stepperLeft.setSpeed(0);
  stepperRight.setSpeed(0);
  stepperLeft.runSpeed();
  stepperRight.runSpeed();
  delay(100);
//while second limit switch not hit
  while (limitState2 == HIGH) {
    //keep reading and moving towards it until hit
    limitState2 = digitalRead(3);
    stepperLeft.setSpeed(-1000);
    stepperRight.setSpeed(-1000);
    stepperLeft.runSpeed();
    stepperRight.runSpeed();
  }
  //stop
  stepperLeft.setSpeed(0);
  stepperRight.setSpeed(0);
  stepperLeft.runSpeed();
  stepperRight.runSpeed();
  //move slightly in towards the middle of the square more - for more accurate movement to D5
  stepperLeft.move(-18);
  stepperRight.move(-18);

  while (stepperLeft.distanceToGo() != 0 || stepperRight.distanceToGo() != 0) {
    stepperLeft.run();
    stepperRight.run();
  }
  delay(100);
}//end runCalibration

void goToD5() {
//gets electromagnet to d5 home square

//calibrate
  runCalibration();
//go to top left square
  moveRank(1.8, 0);
//move diagonally to d5
  moveDiag2forCalibration(-3, 0);
}//end goToD%

void emOn() {
  //turn electromagnet on
  digitalWrite(9, HIGH);
  emState = 1;
  delay(500);
} //end emOn

void emOff() {
  //turn electromagnet off
  digitalWrite(9, LOW);
  emState = 0;
} //end emOff

void displayGamemode() {
  //used for user interface, display gamemode
  lcd.clear();
  lcd.setCursor(0, 0);
  lcd.print("Select Gamemode:");
  lcd.setCursor(0, 1);
  lcd.print(gamemodes[gamemodeIndex]);
  lcd.setCursor(0, 2);
  lcd.print("Black to Scroll");
  lcd.setCursor(0, 3);
  lcd.print("White to Continue");
} //end displayGamemode

void displayTime() {
  //used for user interface, display time control
  lcd.clear();
  lcd.setCursor(0, 0);
  lcd.print("Select Time Control:");
  lcd.setCursor(0, 1);
  if (gamemodeIndex == 2 && timeIndex == 0) timeIndex++;
  lcd.print(times[timeIndex]);
  lcd.setCursor(0, 2);
  lcd.print("Black to Scroll");
  lcd.setCursor(0, 3);
  lcd.print("White to Continue");
} //end displayTime

void displayFriends() {
  //used for user interface, display friend
  lcd.clear();
  lcd.setCursor(0, 0);
  lcd.print("Select Friend:");
  lcd.setCursor(0, 1);
  lcd.print(friends[friendIndex]);
  lcd.setCursor(0, 2);
  lcd.print("Black to Scroll");
  lcd.setCursor(0, 3);
  lcd.print("White to Continue");
} //end displayFriends

void displayGameInfo() {
  //used for user interface, display game info after a game has been seleted
  lcd.clear();
  lcd.setCursor(0, 0);
  lcd.print(gamemodes[gamemodeIndex]);
  lcd.setCursor(0, 1);
  lcd.print(times[timeIndex]);
  if (gamemodeIndex == 0) {
    lcd.setCursor(0, 2);
    lcd.print(friends[friendIndex]);
  }
  lcd.setCursor(0, 3);
  lcd.print("Request Sent-Waiting");
} //end displayGameInfo

void makeAPIRequest(String req) {
  //used to make any GET api request to server
  if (client.connect(server, 443)) {
    Serial.print("Requesting: ");
    Serial.println(req);

    client.print("GET ");
    client.print(req);
    client.println(" HTTP/1.1");
    client.println("Host: lichess.org");
    client.println("Connection: close");
    client.print("Authorization: Bearer ");
    client.println(token);
    client.println();

  }

  else Serial.println("Not connected to server");
}//end makeAPIRequest

void postAPIRequest(String req, String Post) {

  //used to post any api request to server
  //String Post used to add any additional info to api request - used when starting a game with certain conditions
  if (client.connect(server, 443)) {
    Serial.print("Posting: ");
    Serial.println(req);

    client.print("POST ");
    client.print(req);
    client.println(" HTTP/1.1");
    client.println("Host: lichess.org");
    client.println("Connection: close");
    client.print("Authorization: Bearer ");
    client.println(token);
    if (Post.length() != 0) {
      client.println("Content-Type: application/x-www-form-urlencoded");
      client.print("Content-Length: ");
      client.println(Post.length());
    }

    client.println();
    if (Post.length() != 0) {
      client.println(Post);
    }



    Serial.println("Request sent.");
  } else Serial.println("Not connected to server");
}//end postAPIRequest


String toSquare(int row, int col) { 
  //convert 2D array index to a chess square on the board
  //used to take movements on array to moves to send to the game
  char file = 'a' + col;
  char rank = '8' - row;

  return String(file) + String(rank);
}//end toSquare


void initializeArray() {
  //initialize squares and lastsquares arrays
  for (int a = 0; a < 8; a++) {
    for (int b = 0; b < 8; b++) {
      lastsquares[a][b] = 1;
      squares[a][b] = 1;
    }
  }
}//end initializeArray

void fillPrevArray() {
  //fill previous array for reading reed switches
  for (int i = 0; i < 8; i++) {
    for (int j = 0; j < 8; j++) {
      lastsquares[i][j] = squares[i][j];
    }
  }
}//end fillPrevArray
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
void loop() {
  /* -------------------------------------------------------------------------- */



  while (gameStarted == 0) { //if game not started, game selection by the user 


    if (selectingGamemode == 1) { //gamemode selection first
      if (onetime1 == 0) { //used to initially display gamemodes before scrolling/selection
        displayGamemode();
        onetime1++;
      }
      if (digitalRead(3) == LOW) {  // Black button scrolls options
        delay(200);
        gamemodeIndex = (gamemodeIndex + 1) % 2; //change displayed gamemode
        displayGamemode();
      }
      if (digitalRead(2) == LOW) {  // White button selects option
        delay(200);
        if (gamemodeIndex == 0) { //user selected friend game

          selectingGamemode = 0;
          selectingFriends = 1; 
        }

        else { //user selected bot
          selectingGamemode = 0;
          selectingTime = 1;
        }
      }
    } //end selectingGamemode == 1


    if (selectingFriends == 1) { //user selecting a friend
      if (onetime2 == 0) { //used to initially display friends before scrolling/selection
        displayFriends();
        onetime2++;
      }
      if (digitalRead(3) == LOW) {  // Black button scrolls options
        delay(200);
        friendIndex = (friendIndex + 1) % 4; //display next friend
        displayFriends();
      }
      if (digitalRead(2) == LOW) {  // White button selects option
        delay(200);
        if (friendIndex == 3) { //Bcck button, revert to previous selection screen
          selectingGamemode = 1;
          selectingFriends = 0;
          gamemodeIndex = 0;
          friendIndex = 0;
          onetime1 = 0;
          onetime3 = 0;
          onetime2 = 0;
        } else { //friend selected, time control selection now
          selectingFriends = 0;
          selectingTime = 1;
        }
      }
    } //end selectingFriends == 1



    if (selectingTime == 1) { //user selecting the time control 
      if (onetime3 == 0) { //used to initially display time controls before scrolling/selection
        displayTime();
        onetime3++;
      }
      if (digitalRead(3) == LOW) {  // Black button scrolls options
        delay(200);
        timeIndex = (timeIndex + 1) % 5;

        displayTime();
      }
      if (digitalRead(2) == LOW) { //white button to select
        delay(200);
        if (timeIndex == 4) { //BACK pressed
          if (gamemodeIndex == 0) { //if friend game selected, need to go back to friend selection rather than game mode selection because of the extra screen

            selectingTime = 0;
            selectingFriends = 1;
            onetime1 = 0;
            onetime3 = 0;
            onetime2 = 0;
            timeIndex = 0;
            friendIndex = 0;
          } else { //go back to gamemode selection
            selectingTime = 0;
            selectingGamemode = 1;
            onetime1 = 0;  //onetime1
            onetime3 = 0;
            onetime2 = 0;
            gamemodeIndex = 0;
            timeIndex = 0;
          }
        } 
        else { //not back 

          int piecesNotInPosition = 1;

          while (piecesNotInPosition > 0) { //WHILE the pieces on the board are not in the starting position
          //if pieces are not detected on starting squares keep looping and updating the remaining squares
          //display remaining undetected squares using the initialBoardState function 
            fillArray(); //keep filling array 
            piecesNotInPosition = initialBoardState();
          }

          delay(300);
          lcd.clear();
          displayGameInfo(); //display the game info to the user
         
         
          //GAME REQUEST TO BE SENT

          String Post = ""; //any info to be sent to server, like time controls etc
          //clock.limit - total time each side gets to start
          //clock.increment - time increment
          //keepAliveStream - keeps request alive to give a response for when the opponent accepts or declines or times out of challenge
          if (timeIndex == 2) {
            Post = Post + "clock.limit=3600&clock.increment=20&keepAliveStream=true";
          } else if (timeIndex == 3) {
            Post = Post + "clock.limit=1800&clock.increment=20&keepAliveStream=true";
          } else if (timeIndex == 1) {
            Post = Post + "clock.limit=10800&clock.increment=30&keepAliveStream=true";
          } else Post = "keepAliveStream=true";
          if (gamemodeIndex == 0) {  //FRIENDLY GAME


            postAPIRequest("/api/challenge/" + friends[friendIndex], Post); //send the api request
            delay(500);
            
            String c = read_JSON();
            
            String jsonPart = "";
            int startIndex = c.indexOf('{');
            if (startIndex != -1) {
              // Extract everything from the '{' onward
              jsonPart = c.substring(startIndex);

            } else { //error if not connected to server
              Serial.println("No game.");
              while (true)
                ;
            }
            gameID = getID(jsonPart); //get the game ID, used in future requests
            if (gameID == "") { //game error , should never happen unless issue on server end
              lcd.clear();
              lcd.setCursor(0, 0);
              lcd.print("Request Failed: ");
              lcd.setCursor(0, 1);
              lcd.print(jsonPart);
              lcd.setCursor(0, 2);
              lcd.print(jsonPart.substring(20));
            }
            userColor = getColor(jsonPart); //get the user color for the game
            Serial.println(gameID); //debugging
            Serial.println(userColor);
            Serial.print("\n\n\n\n\n");
            delay(700);
            String dec = ""; //decision (from the opponent)
            while (dec == "") { //read until a decision made, accepted or declined etc
              delay(300);
              String t = read_JSON();
              if (t.length() != 0) { //decision made

                lcd.clear();
                lcd.setCursor(0, 0);
                t = t.substring(t.indexOf('{')); //extract JSON
                Serial.println(t);

                dec = getDecision(t);
                if (dec != "accepted") { //challenge not accepted, notify user and return to game selection sequence
                  lcd.clear();
                  lcd.setCursor(0, 0);
                  lcd.print("Challenge not");
                  lcd.setCursor(0, 1);
                  lcd.print("Accepted...");
                  lcd.setCursor(0, 2);
                  lcd.print("Press White");
                  lcd.setCursor(0, 3);
                  lcd.print("to Return");
                  userColor = "";
                  gameID = "";
                  userColorInt = 0; //reset all parameters
                  while(digitalRead(2)==HIGH); //wait until pressed
                } else { //game accepted
                  lcd.clear();
                  lcd.setCursor(0, 0);
                  lcd.print("Challenge Accepted:");
                  lcd.setCursor(0, 1);
                  lcd.print("You have the");
                  lcd.setCursor(0, 2);
                  lcd.print(userColor + " pieces!"); //color of pieces for user
                  lcd.setCursor(0, 3);
                  lcd.print("Press to continue");
                  delay(1000);
                  if (userColor == "white") { //setup for colors for the game
                    userColorInt = 2; //2 because that is the pin for white button
                    userMove = 1; //user white - user moves first
                    otherColor = 3; //3 because that is the pin for the black button
                  }

                  else { //user is black
                    userColorInt = 3;
                    userMove = 0; //user black - opponent moves first
                    otherColor = 2;
                  }
                  client.stop(); 

                  diagonalNum = 1; //used for recalibration throughout
                  //do all initialization tasks
                  initializeChessBoard();
                  printBoard();
                  gameStarted = 1;
                  emState = 0;
                  //debugging
                  Serial.println(userColor);
                  Serial.println(userColorInt);
                  Serial.println(userMove);
                }
              }
            }
          }
          if (gamemodeIndex == 1) { //if bot

            Post = Post + "&level=6&color=white"; //level 6 bot 
            postAPIRequest("/api/challenge/ai", Post); //send api request
            delay(500);
            String c = read_JSON();
            String jsonPart = "";
            int startIndex = c.indexOf('{'); //extract JSON
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
